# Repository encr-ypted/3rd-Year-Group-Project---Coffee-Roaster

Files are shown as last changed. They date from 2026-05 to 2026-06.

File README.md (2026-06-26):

# Smart Coffee Roaster

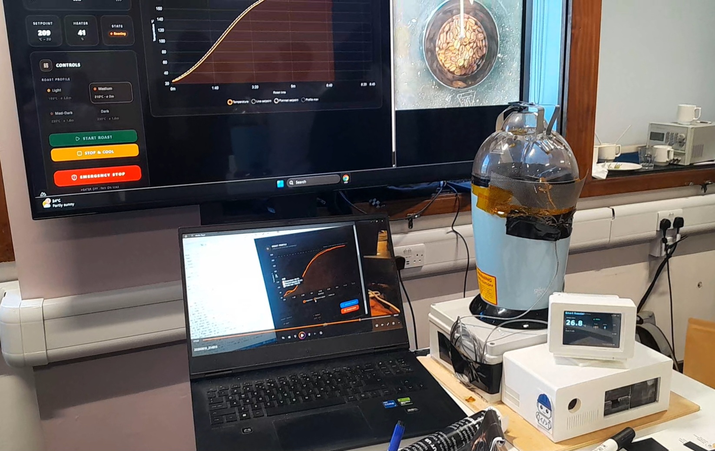
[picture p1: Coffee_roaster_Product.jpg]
Complete Smart Coffee Roaster


> **A low-cost AI-enabled Smart Coffee Roaster developed as part of a third-year Electronic Engineering group project sponsored by IBM.**

The project combines **embedded systems**, **power electronics**, **control engineering**, **computer vision**, **web technologies**, and **artificial intelligence** to create an intelligent small-batch coffee roasting platform capable of automatically executing roast profiles while monitoring and logging the roasting process in real time.

---

# Table of Contents

- [Overview](#overview)
- [Project Objectives](#project-objectives)
- [Final System Features](#final-system-features)
- [Final Prototype](#final-prototype)
- [Power & Embedded Electronics Architecture](#power--embedded-electronics-architecture)
- [Control System](#control-system)
- [Dashboard](#dashboard)
- [Computer Vision & AI](#computer-vision--ai)
- [Hardware](#hardware)
- [Repository Structure](#repository-structure)
- [Detailed Backend Documentation](#detailed-backend-documentation)
- [Future Development](#future-development)
- [Team Members](#team-members)
- [Sponsor](#sponsor)
- [Disclaimer](#disclaimer)

---

# Overview

Coffee roasting is a highly dynamic thermal process where temperature, airflow and bean properties continuously change throughout the roast. Achieving consistent roast quality requires accurate temperature measurement together with precise heater and airflow control.

This project began with a commercially available **hot-air popcorn popper** before being extensively redesigned into a complete embedded coffee roasting platform.

The final system integrates:

- Adaptive Model Predictive Control (MPC)
- Automatic preheating
- Automatic bean-drop detection
- Closed-loop heater control
- Variable-speed blower control
- Live browser dashboard
- Roast profile execution
- Roast data logging
- Raspberry Pi camera monitoring
- Computer vision using grayscale analysis
- Multiple hardware and software safety systems

The primary objective of the project was to develop an accessible and low-cost coffee roasting platform capable of producing more consistent roasts while demonstrating modern embedded control techniques.

---

---

# Overall System Architecture

The Smart Coffee Roaster consists of four primary subsystems:

1. Embedded Control
2. Power Electronics
3. Computer Vision
4. User Interface

The interaction between these subsystems is shown below.

```text
                         ┌──────────────────────────┐
                         │      Web Dashboard       │
                         │  (Vue.js Frontend)       │
                         └────────────┬─────────────┘
                                      │
                            WebSocket / REST API
                                      │
                                      ▼
                         ┌──────────────────────────┐
                         │     FastAPI Backend      │
                         │     (webserver.py)       │
                         └──────┬──────────┬────────┘
                                │          │
                    Commands     │          │ Telemetry
                                ▼          ▲
                     ┌────────────────────────────┐
                     │      MPC Controller        │
                     │      (MPC_Control.py)      │
                     └──────┬────────────┬────────┘
                            │            │
                 Heater PWM │            │ Fan PWM
                            ▼            ▼
                      ┌────────┐    ┌────────┐
                      │ Heater │    │ Blower │
                      └────┬───┘    └────┬───┘
                           │             │
                           └──────┬──────┘
                                  ▼
                       ┌────────────────────┐
                       │ Coffee Roaster     │
                       │ & Roasting Chamber │
                       └─────────┬──────────┘
                                 │
                      Bean Temperature
                                 │
                                 ▼
                     ┌────────────────────┐
                     │ K-Type Thermocouple│
                     │     + MAX31855     │
                     └─────────┬──────────┘
                               │
                               ▼
                      Temperature Feedback

             ┌────────────────────────────────────────┐
             │ Raspberry Pi Camera                    │
             └────────────────┬───────────────────────┘
                              │
                              ▼
                     grayscale.py
                              │
                     Mean Grayscale
                              │
                              ▼
                     MPC Controller
```

The controller continuously receives temperature measurements from the thermocouple while simultaneously monitoring bean colour using the Raspberry Pi camera. The FastAPI backend acts as the communication layer between the embedded controller and the browser dashboard, streaming telemetry and forwarding user commands. The Adaptive Model Predictive Controller (MPC) calculates the optimum heater output every second while controlling the blower motor and logging roast data throughout the roasting process.

# Project Objectives

The objectives of this project were to:

- Design and manufacture a safe embedded coffee roasting system.
- Develop a closed-loop temperature controller capable of accurately tracking roast profiles.
- Investigate Model Predictive Control (MPC) for coffee roasting.
- Integrate computer vision for roast monitoring.
- Develop a modern browser-based user interface.
- Improve roast consistency while maintaining a low overall system cost.
- Produce a modular platform suitable for future AI-assisted roast optimisation.

---

# Final System Features

## Embedded Control

- Raspberry Pi based control system
- Closed-loop heater control
- Variable-speed blower control
- Automatic preheat sequence
- Automatic bean-drop detection
- Adaptive Model Predictive Control
- Automatic cooling mode
- Emergency stop functionality

## User Interface

- Browser-based dashboard
- Live temperature graph
- Planned roast profile
- Actual roast profile
- Roast profile presets
- Heater output display
- Fan state display
- Camera livestream
- Roast logging

## Computer Vision

- Raspberry Pi Camera integration
- Bean detection
- Region-of-interest extraction
- Mean grayscale calculation
- Roast monitoring

## Safety

- Hardware emergency stop
- Software emergency stop
- Over-temperature protection
- Fan fail-safe design
- Isolated high-voltage enclosure
- Separate low-voltage control enclosure

---

# Final Prototype

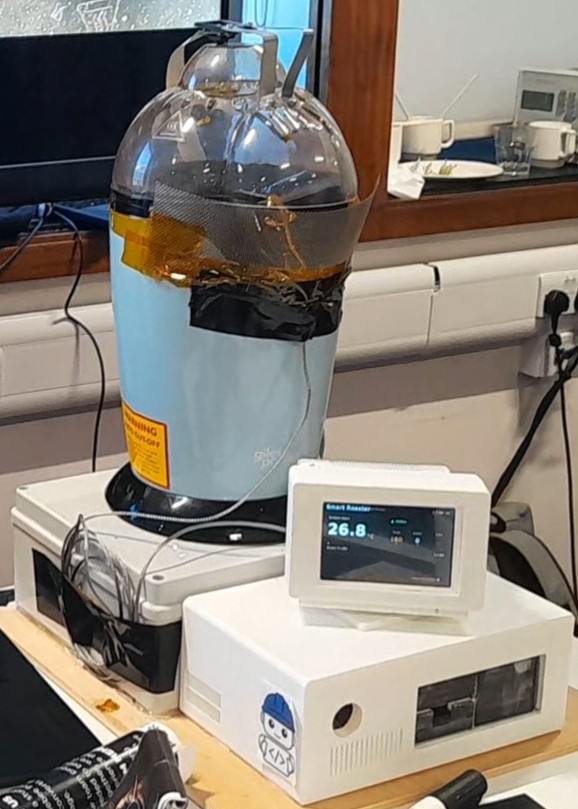
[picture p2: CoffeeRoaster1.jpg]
Complete Prototype


The completed prototype integrates the roasting chamber, embedded electronics, screen display, Raspberry Pi camera and browser-based dashboard into a fully functional coffee roasting system.

The Raspberry Pi continuously monitors bean temperature using a K-type thermocouple before executing the selected roast profile using an Adaptive Model Predictive Controller (MPC). Throughout the roast, telemetry is streamed to the dashboard where the user can monitor live temperature, heater output, fan state, roast progress and the camera feed.

All roast data is logged for later analysis and future controller development.

---

# Power & Embedded Electronics Architecture

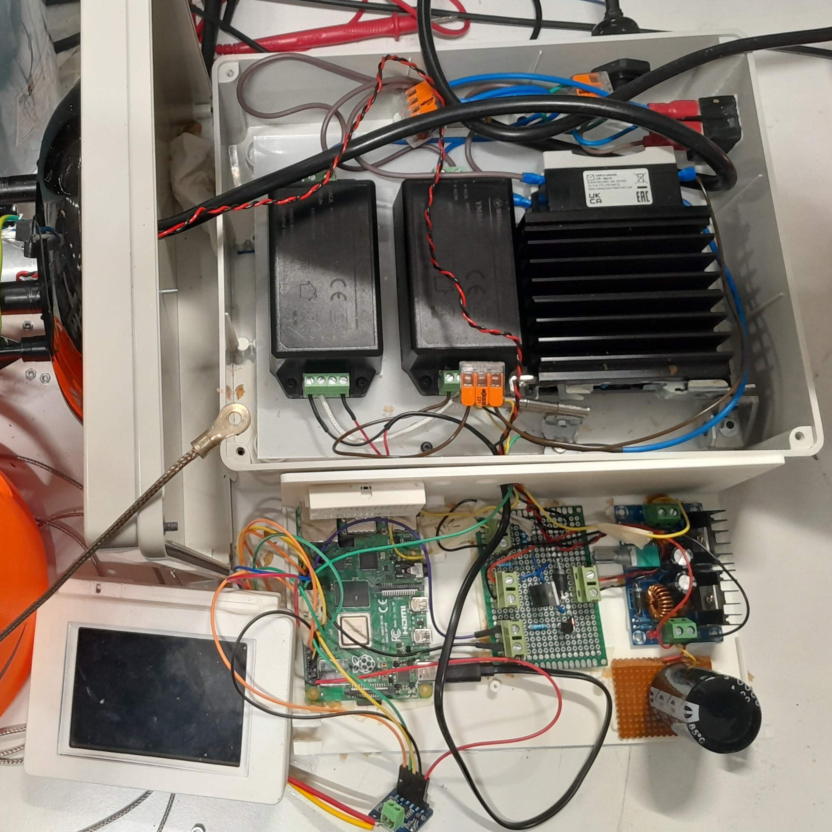
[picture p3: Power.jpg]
Power Electronics Architecture


To improve electrical safety and simplify maintenance, the electronics were deliberately divided into separate **high-voltage** and **low-voltage** enclosures.

This separation prevents hazardous mains wiring from being mixed with sensitive control electronics while reducing electrical interference and improving serviceability.

## High-Voltage Enclosure

The upper enclosure contains every mains-powered component used by the roasting system, including:

- AC → 24 V DC power supply for the blower motor
- AC → 5 V DC power supply for the Raspberry Pi
- Solid State Relay (SSR)
- Aluminium heatsink mounted to the SSR
- Heater switching circuitry
- Mains wiring
- Terminal blocks

The Solid State Relay allows the Raspberry Pi to safely switch the heating element while maintaining complete electrical isolation from the mains supply.

Because the SSR dissipates heat during operation, it is mounted to an aluminium heatsink to maintain safe operating temperatures during long roasting cycles.

Locating every mains-powered component inside a dedicated enclosure significantly reduces the risk of accidental contact with hazardous voltages while making the electrical system considerably easier to maintain and troubleshoot.

---

## Low-Voltage Control Enclosure

The lower enclosure contains all embedded control electronics responsible for monitoring and controlling the roasting process.

Components include:

- Raspberry Pi 4
- MAX31855 thermocouple interface
- Custom motor driver Circuit
- Raspberry Pi screen display
- 24 V → 6.2 V buck converter supplying the blower motor
- Large smoothing capacitor connected to the buck converter output

The buck converter efficiently steps the 24 V supply down to approximately **6.2 V** for the blower motor.

A large output smoothing capacitor is connected across the converter output to reduce voltage ripple and improve supply stability during rapid motor load changes.

The separation between high-voltage and low-voltage electronics also improves measurement stability by reducing electrical noise reaching the thermocouple interface and Raspberry Pi.

# Custom Motor Driver

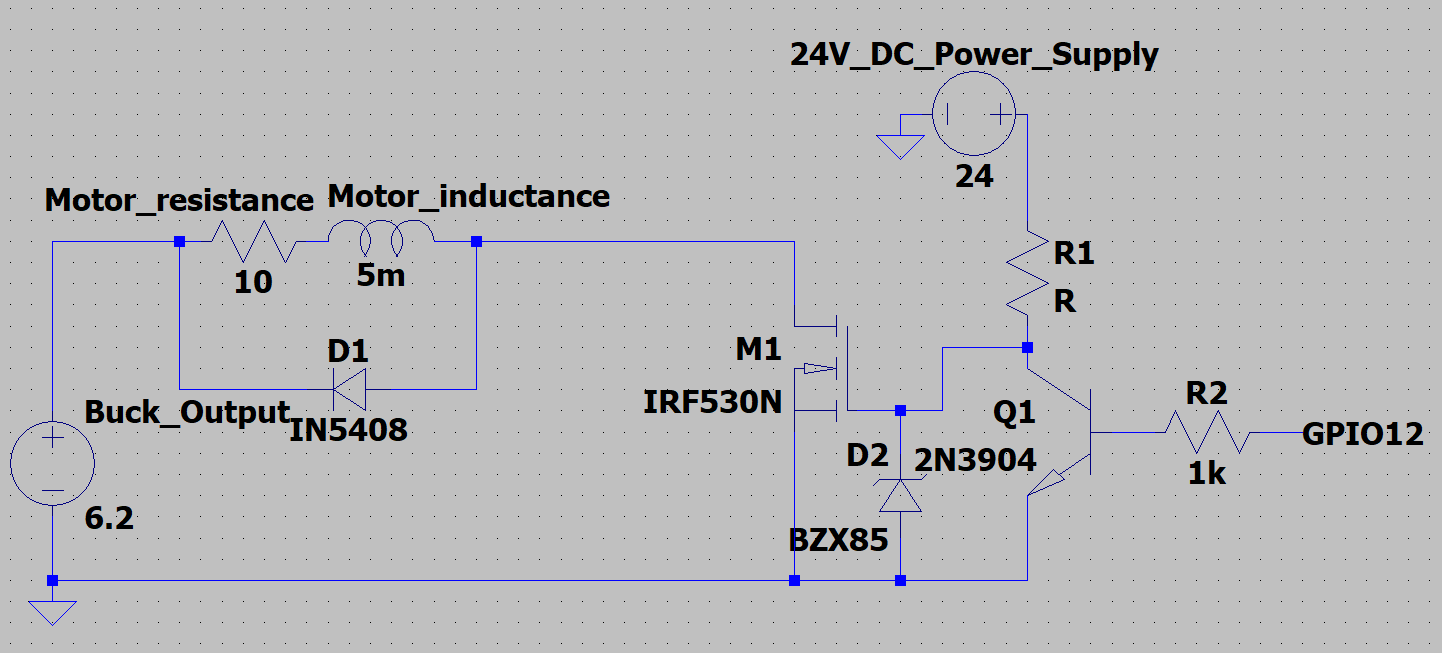
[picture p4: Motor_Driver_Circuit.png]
Motor Driver Circuit


Rather than using a commercial motor driver module, a custom Circuit was designed specifically for the requirements of this project.

The driver controls the fan motor while incorporating additional hardware safety features that operate independently of the Raspberry Pi software.

## BJT Fail-Safe Design

One of the primary safety considerations during development was ensuring continuous airflow over the heater.

If the Raspberry Pi were to crash, lose power or become disconnected while the heater remained hot, stopping the fan (blower) could allow excessive temperatures to develop inside the roasting chamber, which results in melting the fan.

To minimise this risk, the motor driver incorporates a **BJT-based fail-safe circuit**.

The circuit is designed so that:

- During normal operation the Raspberry Pi controls the fan speed.
- If the Raspberry Pi loses power or becomes disconnected, the control transistor automatically defaults the fan **ON**.
- Continuous airflow cools the heater while preventing excessive heat build-up inside the roasting chamber.

Unlike software safety mechanisms, this protection remains operational even if the Raspberry Pi itself has failed, providing an additional hardware layer of protection.

---

# Control System

Temperature is measured using a **K-type thermocouple** connected to a **MAX31855 thermocouple interface**.

The roasting process is controlled using an **Adaptive Model Predictive Controller (MPC)** rather than a conventional PID controller.

Coffee roasting is a challenging control problem because:

- the system exhibits significant thermal inertia,
- heater power takes several seconds to affect bean temperature,
- bean properties continuously change throughout the roast,
- moisture evaporates,
- airflow conditions vary,
- heat losses change over time.

A controller that reacts only to the current temperature error therefore struggles to accurately follow a continuously changing roast profile.

Instead, the implemented MPC predicts how the bean temperature will evolve in the future before selecting the optimum heater output.

The controller performs:

- Automatic chamber preheating
- Automatic bean-drop detection
- Future roast profile prediction
- Heater optimisation
- Adaptive thermal model updating
- Overshoot minimisation
- Smooth heater control
- Automatic cooling mode

Every second the controller:

1. Reads the current bean temperature.
2. Predicts future bean temperatures across the prediction horizon.
3. Generates the future sigmoid roast-profile setpoints.
4. Evaluates every possible heater duty cycle.
5. Calculates the optimisation cost for every candidate.
6. Selects the heater output with the minimum predicted cost.
7. Applies the selected heater duty cycle.
8. Updates the adaptive thermal model when required.

As roasting progresses, the thermal behaviour of the beans changes due to moisture evaporation, changing bean density and varying airflow conditions.

To compensate for these effects, the controller continuously adapts its thermal model by updating the heater effectiveness parameter whenever sustained prediction errors are observed.

This enables the controller to maintain accurate temperature prediction throughout the roast.

The complete mathematical derivation, optimisation equations, thermal model and implementation are documented separately in the backend documentation: [`Backend_Final_Version/README.md`](Backend_Final_Version/README.md).

---

# Dashboard

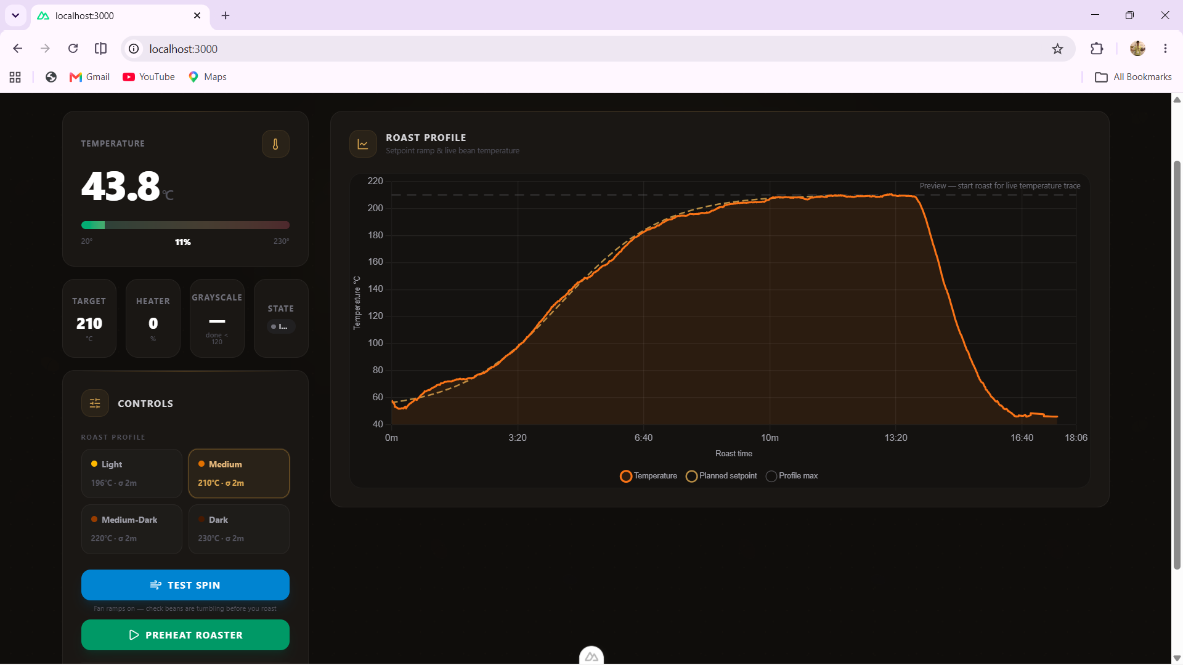
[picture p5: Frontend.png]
Frontend


A browser-based dashboard was developed to provide complete control and monitoring of the roasting process.

The interface communicates directly with the Raspberry Pi backend using WebSockets, allowing telemetry to be updated in real time.

The dashboard displays:

- Live bean temperature
- Planned roast profile
- Actual roast profile
- Heater duty cycle
- Fan duty cycle
- Current operating state
- Roast timer
- Roast presets

The user can also:

- Start a roast
- Stop and cool the roast
- Perform an emergency stop
- Test the fan (blower) motor
- Select predefined roast profiles

All roast telemetry is continuously logged and stored for later analysis.

---

# Computer Vision & AI

A Raspberry Pi Camera continuously monitors the roasting chamber throughout the roast.

Current functionality includes:

- Live video streaming
- Bean detection
- Region-of-interest extraction
- Mean grayscale calculation
- Roast monitoring
- Roast logging

The average bean grayscale value is continuously calculated and compared against profile-dependent thresholds.

This information can be used to notify the operator when the beans appear to have reached the desired roast level.

The vision system has been deliberately separated from the main controller so that camera failures cannot interrupt heater control or other safety-critical functions.

The software architecture also allows future integration of machine learning models capable of automatically classifying roast level and recommending or terminating roasts.

---

# Hardware

The completed prototype consists of:

## Mechanical

- Modified hot-air popcorn popper
- Custom PETG blower fan
- 3D printed mechanical components
- Protective electronics enclosures

## Embedded Electronics

- Raspberry Pi 4
- Raspberry Pi Camera
- Raspberry Pi screen display
- MAX31855 thermocouple interface
- K-type thermocouple
- Custom motor driver Circuit

## Power Electronics

- AC → 24 V DC power supply
- AC → 5 V DC power supply
- Solid State Relay (SSR)
- Aluminium heatsink
- 24 V → 6.2 V buck converter
- Output smoothing capacitor

---

# Repository Structure

```text
.
├── README.md                         <- Main project overview
│
├── backend_final_version/
│   ├── README.md                     <- Detailed MPC documentation
│   ├── MPC_Control.py
│   ├── grayscale.py
│   ├── webserver.py
│   ├── st7796.py
│   └── ...
│
├── blog/
│   ├── progress-update-7th-may.md
│   ├── progress-update-21st-may.md
│   └── progress-update-7th-june.md
│
├── Coffee_roaster_Product.jpg
├── Power.jpg
└── ...
```

## Detailed Backend Documentation

The backend implementation, including:

- Adaptive Model Predictive Control (MPC)
- Thermal model
- Optimisation equations
- Software architecture
- FastAPI backend
- Dashboard communication
- Camera processing
- Backend safety systems

is documented in:

➜ **[`Backend_Final_Version/README.md`](Backend_Final_Version/README.md)**

# Future Development

Although the current system is fully functional, several opportunities exist for future improvement.

Potential future work includes:

- Automatic roast completion using computer vision
- Convolutional Neural Network (CNN) based roast-level classification
- Automatic roast profile optimisation using machine learning
- Roast profile recommendation based on previous roasting data
- Multi-sensor thermal modelling
- Automatic parameter tuning for the MPC controller
- Cloud-based roast logging and analytics
- Remote monitoring and control
- Mobile application integration
- Expansion to larger-capacity roasting systems

The modular hardware and software architecture developed during this project was intentionally designed to support these future extensions with minimal modification to the existing control system.

---

# Sustainability

Coffee roasting is traditionally a highly experience-dependent process where inconsistent temperature control can result in wasted batches of coffee.

This project aims to improve sustainability by:

- Reducing roasting waste through improved temperature control
- Improving roast repeatability
- Providing an accessible low-cost roasting platform
- Supporting small-batch roasting
- Reducing unnecessary energy consumption through adaptive heater control
- Providing detailed roast data for process optimisation

The use of Model Predictive Control (MPC) further improves energy efficiency by applying only the heater power required to accurately follow the desired roast profile rather than continuously oscillating around the target temperature.

---

# Learning Outcomes

This project involved the integration of multiple engineering disciplines, including:

- Embedded Systems
- Control Engineering
- Power Electronics
- Software Engineering
- Computer Vision
- Mechanical Design
- 3D Printing
- Data Logging
- Web Development

The final prototype demonstrates the successful integration of these disciplines into a complete embedded coffee roasting platform.

---

# Project Outcome

The project successfully produced a fully operational AI-enabled smart coffee roaster capable of:

- Automatic preheating
- Automatic bean-drop detection
- Closed-loop temperature control
- Adaptive Model Predictive Control
- Roast profile tracking
- Live dashboard monitoring
- Camera-based roast monitoring
- Roast logging
- Automatic cooling
- Hardware and software safety mechanisms

Multiple successful roasting trials were completed throughout the project, demonstrating accurate temperature tracking and repeatable roast profile execution.

The completed system provides a modular platform suitable for continued research into intelligent coffee roasting and future AI-assisted optimisation techniques.

---

# Team Members

This project was completed by:

- Sami Marouf
- Tayo Babs-Olugbemi
- Rojan Ragunathan
- Patanwit Sawatyanon
- Yikai Su
- Peter Z Wang

---

# Sponsor

This project was completed as part of a third-year Electronic Engineering Group Design Project with sponsorship and support from **IBM**.

IBM provided industrial guidance throughout the project, helping shape the system requirements, design process and final implementation.

---

# Acknowledgements

The team would like to thank:

- IBM for sponsoring and supporting the project.
- The Department of Electronic Engineering for providing laboratory facilities and technical guidance.
- The project supervisor and lab technicians for their continuous feedback throughout the design and testing process.

---

# Disclaimer

This project interfaces with **mains electricity**, **high temperatures**, and **moving mechanical components**.

The prototype was developed for educational and research purposes.

Although numerous hardware and software safety mechanisms were incorporated—including electrical isolation, emergency stop functionality, over-temperature protection, hardware blower fail-safe circuitry and automatic cooling—the system should only be operated using appropriate electrical protection and under suitable supervision.

The authors accept no responsibility for any damage or injury resulting from attempts to reproduce or operate this system without appropriate engineering knowledge and safety precautions.

---

# Detailed Backend Documentation

The complete backend implementation—including:

- Adaptive Model Predictive Control (MPC)
- Mathematical derivation of the controller
- Thermal process model
- Optimisation cost function
- Adaptive thermal model
- FastAPI backend
- Dashboard communication
- Camera processing pipeline
- Safety mechanisms
- Backend architecture

is documented separately in:

## ➜ **[`Backend_Final_Version/README.md`](Backend_Final_Version/README.md)**

This document provides a detailed explanation of the control algorithms, mathematical equations, software architecture and implementation used by the Smart Coffee Roaster.

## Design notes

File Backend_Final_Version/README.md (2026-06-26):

# Smart Coffee Roaster Backend

This folder contains the Raspberry Pi backend for the Smart Coffee Roaster. It controls the roast process, communicates with the frontend, monitors bean brightness with the camera, and can drive the optional LCD display.

## Files

### `MPC_Control.py`

The main roast-control script.

It:
- Reads temperature from the MAX31855 thermocouple.
- Controls the heater and fan.
- Handles preheating, bean-drop detection, and the normal roast phase.
- Uses a model predictive control (MPC) loop to follow the selected roast profile's setpoint curve.
- Writes roast telemetry to CSV files in `logs/`.
- Reads grayscale data from `grayscale_state.json`.
- Sends a roast-done notification flag when grayscale stays below the selected profile threshold for five seconds.

The grayscale notification does not automatically stop the roast, turn off the heater, or start cooling.

### `grayscale.py`

A separate camera worker for the Raspberry Pi AI camera.

It:
- Starts the camera and AI detector.
- Captures bean images.
- Calculates the average bean brightness (`mean_grayscale`).
- Writes the latest value to `grayscale_state.json`.

It runs separately from `MPC_Control.py` so camera errors, timeouts, or crashes do not interrupt the main heating, fan, thermocouple, or MPC control logic.

A grayscale value ranges from approximately 0 to 255:
- Lower values mean darker beans.
- Higher values mean lighter beans.

### `webserver.py`

The FastAPI/WebSocket backend used by the frontend.

It:
- Provides roast profiles at `/api/profiles`.
- Sends live telemetry through `/ws/telemetry`.
- Reads the newest CSV file in `logs/`.
- Sends temperature, setpoint, heater output, fan output, grayscale, roast state, and roast-done notification status to the frontend.
- Writes commands to `roaster_command.json`.

### `st7796.py`

Driver for the ST7796 SPI LCD display.

It uses SPI1 so it does not conflict with the MAX31855 thermocouple on SPI0.

### `requirements.txt`

Python dependencies for the backend.

## Adaptive Model Predictive Control (MPC)

The Smart Coffee Roaster uses an **Adaptive Model Predictive Controller (MPC)** to regulate bean temperature throughout the roast. Unlike a conventional PID controller, which reacts only to the current temperature error, the MPC predicts the future thermal behaviour of the roaster before selecting the optimum heater output. This approach is particularly well suited to coffee roasting because the process exhibits significant thermal inertia and transport delay, meaning changes in heater power may take several seconds to influence bean temperature.

At every one-second control interval, the controller predicts how the bean temperature will evolve over a finite prediction horizon using a first-order discrete thermal model. Multiple candidate heater outputs are evaluated, and the one producing the lowest overall cost is selected and applied for the next control interval. This optimisation process is repeated every second throughout the roast.

### Thermal Process Model

The roaster is approximated using the first-order discrete thermal model

$$
T_{k+1}=T_{amb}+A(T_k-T_{amb})+Bu_k
$$

where:

* **Tₖ** = current bean temperature
* **Tₖ₊₁** = predicted bean temperature one second later
* **Tₐₘᵦ** = ambient temperature
* **uₖ** = heater duty cycle (%)
* **A** = heat retention coefficient
* **B** = heater effectiveness coefficient

The first term represents the ambient temperature surrounding the roaster.

The second term models the thermal inertia of the roasting system by describing how much of the previous temperature is naturally retained between consecutive control intervals.

The third term represents the heating contribution from the electric heater. Larger heater duty cycles produce greater increases in predicted bean temperature.

Rather than using this model only once, the MPC repeatedly evaluates it to predict the complete future temperature trajectory.

### Future Setpoint Prediction

Instead of assuming the future target temperature remains equal to the current setpoint, the controller predicts the actual future roast profile.

For every prediction step,

$$
r_{k+i}=\text{SetpointCurve}(t+i)
$$

where:

* **rₖ₊ᵢ** = desired future temperature
* **t** = current roast time
* **i** = prediction step

This allows the controller to anticipate future temperature changes before they occur. As the sigmoid roast profile continues to rise, the MPC can begin increasing heater power in advance rather than waiting until the setpoint has already changed.

### Prediction Horizon

For each control interval, the controller predicts bean temperature over a finite prediction horizon of approximately one minute.

For every candidate heater duty cycle between **0% and 100%**, the thermal model is recursively evaluated to generate the complete future temperature trajectory

$$
{T_{k+1},T_{k+2},...,T_{k+N}}
$$

where **N** is the prediction horizon.

This enables the controller to compare the long-term consequences of different heater outputs rather than considering only the next measurement.

### Candidate Heater Evaluation

At every control update, the controller evaluates every possible heater duty cycle from **0% to 100%**.

For each candidate heater output:

1. The future roast-profile setpoints are generated.
2. Future bean temperatures are predicted across the prediction horizon.
3. A total optimisation cost is calculated.
4. The controller stores the total cost.

After all candidate heater outputs have been evaluated, the heater duty cycle with the lowest predicted cost is selected and applied.

Mathematically,

$$
u^*=\arg\min_u J(u)
$$

where **u*** represents the optimum heater duty cycle.

### Cost Function

Each candidate heater output is assigned a cost according to

$$
J=\sum_{k=1}^{N}w_t(r_k-T_k)^2+\sum_{k=1}^{N}w_oO_k^2+w_h(u_k-u_{k-1})^2
$$

where:

* **wₜ** = tracking-error weighting
* **wₒ** = overshoot weighting
* **wₕ** = heater-change weighting

#### Tracking Error

The first term

$$
\sum_{k=1}^{N}w_t(r_k-T_k)^2
$$

penalises deviation between the predicted bean temperature and the desired roast profile throughout the prediction horizon. Larger tracking errors produce larger costs, encouraging the controller to follow the planned roast profile as accurately as possible.

#### Overshoot Penalty

The second term

$$
\sum_{k=1}^{N}w_oO_k^2
$$

penalises predicted overshoot above the desired roast profile.

Only temperatures exceeding the target contribute to this penalty, discouraging overheating while still allowing aggressive heating when the measured temperature remains below the desired profile.

#### Heater Smoothness

The third term

$$
w_h(u_k-u_{k-1})^2
$$

penalises large changes in heater duty cycle between consecutive control intervals.

Without this penalty, the optimiser may rapidly increase and decrease heater power, producing oscillatory behaviour. Penalising abrupt heater changes results in smoother control actions, reduced actuator switching, and improved thermal stability.

### Adaptive Thermal Model

Coffee roasting is not a constant thermal process.

During roasting:

- moisture evaporates,
- bean density decreases,
- airflow characteristics change,
- heat losses vary,
- the effectiveness of the heater changes.

Consequently, a fixed thermal model gradually becomes inaccurate.

To compensate, the controller continuously compares predicted and measured temperatures.

If a sustained prediction error is detected, the heater effectiveness coefficient (**B**) is automatically adjusted within predefined minimum and maximum limits.

If the measured temperature rises faster than predicted, the controller increases **B**, indicating that the heater is more effective than previously estimated.

If the measured temperature rises more slowly than predicted, **B** is reduced.

This adaptive mechanism continually improves model accuracy throughout the roast while preventing unrealistic parameter values.

### Bean-Drop Detection

Before roasting begins, the chamber is preheated to the selected temperature.

When green coffee beans are added, the thermocouple detects the characteristic temperature drop caused by the colder beans entering the chamber.

The controller automatically identifies this event, temporarily suspends normal roast control, waits until the temperature reaches its minimum, and detects the point at which the beans begin warming again.

At this instant:

- the roast timer is reset,
- the sigmoid roast profile begins,
- the MPC controller becomes active.

This ensures the roast profile is synchronised with the true start of bean heating rather than the preheating stage.

### Control Cycle

Every second the controller performs the following sequence:

1. Read the current bean temperature from the thermocouple.
2. Generate future sigmoid roast-profile setpoints.
3. Predict future bean temperatures for every candidate heater output.
4. Calculate the optimisation cost for every candidate.
5. Select the heater duty cycle producing the minimum cost.
6. Apply the selected heater output.
7. Update the adaptive heater-effectiveness coefficient if required.
8. Record telemetry for the dashboard and CSV log files.

This optimisation process repeats continuously throughout the roast, allowing the controller to accurately track a continuously changing roast profile while automatically compensating for changing thermal dynamics.

## Roast Flow

1. The empty roasting chamber is preheated.
2. Once the preheat temperature is stable, beans are added.
3. The added beans create a temperature drop.
4. The controller detects the drop, turns the heater off, and waits for the lowest temperature.
5. Once the temperature begins rising again, the actual roast starts.
6. The controller resets roast time and follows the MPC setpoint curve toward the chosen profile target.

## Grayscale Roast-Done Notification

The camera worker measures the average brightness of the beans and writes it to `grayscale_state.json`.

During the actual roast, `MPC_Control.py` compares that value against the selected profile threshold:

| Roast profile | Notification threshold |
|---|---:|
| Light | Below 120 |
| Medium | Below 115 |
| Medium-Dark | Below 110 |
| Dark | Below 105 |

If the grayscale value remains below the selected threshold for five seconds, the backend sets `roast_done` to `true`. The frontend can then display a notification that the roast looks done.

This is notification-only. The user still decides when to stop and cool the roast.

## Running the Backend

Open three terminals on the Raspberry Pi.

### 1. Start the grayscale worker

```bash
source venv/bin/activate
python grayscale.py
```

This writes live camera data to:

```text
grayscale_state.json
```

### 2. Start the roast controller

```bash
source venv/bin/activate
python MPC_Control.py
```

This controls the thermocouple, heater, fan, preheat sequence, bean-drop detection, MPC setpoint curve, and roast logging.

### 3. Start the web server

```bash
source venv/bin/activate
python webserver.py
```

The server runs on port `8000`.

### 4. Start the screen display

```bash
source venv/bin/activate
python lcd.py
```

## Generated Files

### `roaster_command.json`

Written by `webserver.py` and read by `MPC_Control.py`.

Example:

```json
{
  "command": "PREHEAT",
  "target_c": 210.0,
  "profile_id": "medium"
}
```

### `grayscale_state.json`

Written by `grayscale.py` and read by `MPC_Control.py`.

Example:

```json
{
  "timestamp": 1712345678.2,
  "mean_grayscale": 94.7,
  "ok": true,
  "error": null
}
```

### `logs/roast_*.csv`

Created by `MPC_Control.py`.

Each CSV row includes time, temperature, target, setpoint, heater output, fan speed, grayscale value, grayscale threshold, roast-done notification status, and control state.

## Safety Notes

- The grayscale system is notification-only and must not replace operator judgement.
- The emergency-stop and over-temperature safety behavior remain in `MPC_Control.py`.
- If the camera worker stops, the main roast controller continues running. Grayscale will appear unavailable until the worker starts writing fresh values again.

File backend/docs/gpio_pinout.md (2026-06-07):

# Raspberry Pi GPIO pinout — Coffee Roaster

Wiring reference for the **40-pin Raspberry Pi header**. All GPIO numbers are **BCM** (Broadcom), not board/WiringPi numbering.

Physical pin numbers match the standard Pi pinout (pin 1 = 3.3 V at the corner near the SD card, odd pins on the left column).

Config source: `config.py` (heater, fan, thermocouple) and `hardware/display/st7796.py` (LCD).

---

## Quick reference — all used pins

| Component | Signal | BCM GPIO | Physical pin | SPI / bus |
|---|---|---|---|---|
| **Heater** | SSR control | **23** | **16** | — |
| **Fan** | PWM speed | **12** | **32** | — |
| **Thermocouple** | CS (CE1) | **7** | **26** | SPI0 |
| **Thermocouple** | SCLK | **11** | **23** | SPI0 |
| **Thermocouple** | MISO (DO) | **9** | **21** | SPI0 |
| **Thermocouple** | MOSI | **10** | **19** | SPI0 (shared; MAX31855 reads via MISO) |
| **LCD** | CS | **17** | **11** | SPI1 (`/dev/spidev1.0`) |
| **LCD** | MOSI (SDI) | **20** | **38** | SPI1 |
| **LCD** | SCLK (SCK) | **21** | **40** | SPI1 |
| **LCD** | MISO (SDO) | **19** | **35** | SPI1 (optional) |
| **LCD** | DC / RS | **25** | **22** | — |
| **LCD** | RESET / RST | **24** | **18** | — |
| **LCD** | Backlight (BL) | **22** | **15** | — |
| **Power** | 3.3 V (sensors, LCD) | — | **1** or **17** | — |
| **Power** | 5 V (if module needs it) | — | **2** or **4** | — |
| **Ground** | Common GND | — | **6**, **9**, **14**, **20**, **25**, **30**, **34**, **39** | — |

**12 GPIO lines used** (7, 9, 10, 11, 12, 17, 20, 21, 22, 23, 24, 25). MISO on GPIO 19 is optional for the LCD.

---

## Do not use (conflicts)

| BCM GPIO | Physical pin | Why |
|---|---|-----|
| **18** | **12** | Default SPI1 CE0 — remapped to GPIO 17 for this project |
| **8** | **24** | SPI0 CE0 — thermocouple uses **CE1** (GPIO 7) instead |

Do not move the heater to GPIO 18; firmware and docs assume **GPIO 23** (pin 16). LCD backlight is **GPIO 22** (pin 15), not 23.

---

## Heater (SSR)

Solid-state relay driven by time-proportional software (`hardware/devices/heater.py`).

| From | To | BCM GPIO | Physical pin |
|---|-----|---|---|
| Pi GPIO | SSR control input (+) | **23** | **16** |
| Pi GND | SSR control input (−) / module GND | — | e.g. **6**, **14**, **20** |

| Property | Value |
|---|---|
| `config.py` | `HEATER_GPIO = 23` |
| Logic | Active **high** — GPIO high = heater on for the current PWM window |
| Control | ~1 s window, duty 0–100% (`HEATER_CONTROL_WINDOW_S`) |

Use an SSR rated for your heater load. Keep mains wiring separate from low-voltage Pi wiring.

---

## Fan (PWM)

Drum / cooling fan via PWM (`hardware/devices/motor.py`).

| From | To | BCM GPIO | Physical pin |
|---|-----|---|---|
| Pi PWM output | Fan driver (MOSFET gate / PWM input) | **12** | **32** |
| Pi GND | Driver GND | — | any GND |

| Property | Value |
|---|---|
| `config.py` | `FAN_PWM_GPIO = 12`, `FAN_PWM_FREQUENCY_HZ = 1000` |
| Logic | `active_high=False` — software uses inverted PWM; verify spin direction/speed on the bench |
| Default | 100% when on (`FAN_DEFAULT_SPEED = 1.0`) |

GPIO 12 supports hardware PWM (PWM0). Use a suitable transistor or MOSFET if the fan draws more than a few milliamps from the Pi.

---

## Bean temperature (MAX31855 thermocouple)

SPI0 + chip select on CE1 (`hardware/devices/thermocouple.py`, Adafruit MAX31855 library).

### Module → Pi

| MAX31855 label | Pi signal | BCM GPIO | Physical pin |
|---|---|---|---|
| VIN / VCC | 3.3 V | — | **1** or **17** |
| GND | GND | — | e.g. **9**, **14** |
| SCK / CLK | SPI0 SCLK | **11** | **23** |
| CS | SPI0 CE1 | **7** | **26** |
| SO / DO (data out) | SPI0 MISO | **9** | **21** |

| Property | Value |
|---|---|
| `config.py` | `THERMOCOUPLE_CS_GPIO = 7` |
| Device node | Uses `board.SPI()` → `/dev/spidev0.0` with manual CS on GPIO 7 |
| Probe | K-type (or match your breakout board) |

After wiring, confirm SPI0:

```bash
ls /dev/spidev0.0
```

Enable with `dtparam=spi=on` in `/boot/firmware/config.txt` (or `/boot/config.txt` on older OS).

---

## LCD (ST7796, 3.5″ SPI)

Separate **SPI1** bus so LCD traffic does not share SPI0 with the thermocouple (`hardware/display/st7796.py`).

### Required boot config

In `/boot/firmware/config.txt` (Bookworm) or `/boot/config.txt`:

```text
dtparam=spi=on
dtoverlay=spi1-1cs,cs0_pin=17
```

Reboot, then check:

```bash
ls /dev/spidev1.0
```

### LCD module → Pi

| LCD label | Pi signal | BCM GPIO | Physical pin | Notes |
|---|---|---|---|---|
| VCC | 3.3 V | — | **1** or **17** | Use 5 V only if your module docs require it |
| GND | GND | — | e.g. **6**, **9** | |
| CS / LCD_CS | SPI1 CS (remapped) | **17** | **11** | **Not** pin 12 (GPIO 18) |
| RESET / RST | GPIO out | **24** | **18** | |
| DC / RS | GPIO out | **25** | **22** | Data vs command |
| SDI / MOSI | SPI1 MOSI | **20** | **38** | |
| SCK / SCLK | SPI1 SCLK | **21** | **40** | |
| LED / BL | Backlight | **22** | **15** | PWM brightness in software |
| SDO / MISO | SPI1 MISO | **19** | **35** | Optional for display-only |
| Touch (T_*) | — | — | — | Not connected |
| SD card (SD_*) | — | — | — | Not connected |

| Property | Value |
|---|---|
| SPI | Bus **1**, device **0** → `/dev/spidev1.0` |
| Rotation | 90° landscape (default in driver) |

Smoke test: `python hardware/display/st7796.py` (from `backend/` with venv). See also `docs/lcd_st7796_test.md`.

---

## SPI bus summary

```
SPI0 (/dev/spidev0.0)          SPI1 (/dev/spidev1.0)
├── SCLK  GPIO 11  pin 23      ├── SCLK  GPIO 21  pin 40
├── MOSI  GPIO 10  pin 19      ├── MOSI  GPIO 20  pin 38
├── MISO  GPIO  9  pin 21      ├── MISO  GPIO 19  pin 35
├── CE0   GPIO  8  pin 24  (unused)
└── CE1   GPIO  7  pin 26  ← MAX31855 CS
                               └── CS    GPIO 17  pin 11  ← LCD (overlay remap)
```

---

## 40-pin header map (used pins only)

Odd pins (left) and even pins (right), top to bottom:

```
     3.3V [ 1] [ 2] 5V
          [ 3] [ 4] 5V
          [ 5] [ 6] GND
          [ 7] [ 8]
  LCD CS [11] [12] GPIO 18 — do not use for LCD CS
          [13] [14] GND
LCD BL  [15] [16] HEATER GPIO 23
   3.3V [17] [18] LCD RST GPIO 24
TC MOSI [19] [20] GND
TC MISO [21] [22] LCD DC GPIO 25
TC SCLK [23] [24] SPI0 CE0 (unused)
      GND [25] [26] TC CS GPIO 7
          [27] [28]
      GND [29] [30] GND
          [31] [32] FAN PWM GPIO 12
          [33] [34] GND
LCD MISO [35] [36]
          [37] [38] SPI1 MOSI GPIO 20
      GND [39] [40] SPI1 SCLK GPIO 21
```

---

## Changing pins in software

| Setting | File | Key |
|---|---|-----|
| Heater | `config.py` | `HEATER_GPIO` |
| Fan | `config.py` | `FAN_PWM_GPIO` |
| Thermocouple CS | `config.py` | `THERMOCOUPLE_CS_GPIO` |
| LCD CS, RST, DC, BL | `hardware/display/st7796.py` | `LCD_CS`, `LCD_RST`, `LCD_RS`, `LCD_LED` |

If you change LCD CS, update `dtoverlay=spi1-1cs,cs0_pin=...` to match and reboot.

---

## Permissions

The `pi` user (or whichever user runs the service) should be in the `gpio` and `spi` groups:

```bash
sudo usermod -aG gpio,spi pi
```

Reboot or re-login after adding groups.

---

## Related docs

- LCD bring-up: `lcd_st7796_test.md`
- Deploy on Pi: `../deploy/README.md`
- Backend overview: `../README.md`

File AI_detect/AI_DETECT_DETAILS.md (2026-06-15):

# SmartRoast AI Detection Pipeline

## Overview

This module adds the first camera-based AI workflow for the Smart Coffee Roaster project.

The system is designed for a Raspberry Pi 4B connected to a Raspberry Pi camera. The camera is mounted in a fixed position and captures images from inside the roasting chamber. The software crops a fixed region of interest, detects whether coffee beans are present, and then calculates the average grayscale value of the cropped bean region.

The grayscale value is used as an early roast colour indicator. As roasting progresses, the bean region is expected to become darker, so images captured later in the same batch should generally show a lower average grayscale value.

---

## Project Goals

* Test Raspberry Pi camera capture and image-processing behaviour
* Collect real roast image data with batch-aware file names
* Crop a fixed bean region from each captured image
* Prepare labelled datasets for bean/no-bean classification
* Apply data augmentation only to the training set
* Train and compare several lightweight CNN models using PyTorch
* Save the best-performing model locally
* Calculate average grayscale values for roast monitoring
* Generate per-batch grayscale trend plots

---

## Folder Structure

```text
AI_detect/
  01_full_system_test.py      # One-command camera and image-processing test
  02_auto_capture.py          # Timed automatic image capture during roasting
  03_crop_images.py           # Fixed ROI cropping for all captured images
  04_split_dataset.py         # 8:1:1 train/validation/test dataset split
  05_augment_train_set.py     # Training-set-only data augmentation
  06_train_models.py          # PyTorch CNN training and model comparison
  07_plot_gray_trend.py       # Per-batch grayscale trend plotting
  08_predict_image.py         # Single-image model inference
  09_pi_camera_inference.py   # CLI wrapper for live Raspberry Pi inference
  10_test_detector_loop.py    # Reusable detector loop test
  camera_utils.py             # Picamera2, OpenCV, and mock camera helpers
  grayscale_utils.py          # Reusable average grayscale calculation
  model_utils.py              # Shared CNN model definition
  pi_ai_detector.py           # Reusable detector class for backend integration
  model_config.json           # CNN architecture and training configuration
  requirements.txt            # Python dependencies
  raw/                        # Original captured images
  resized/                    # Cropped ROI images
  train_set/
  validate_set/
  test_set/
  train_set_augmented/
  models/
  plot/
  test_outputs/
```

The generated image data, plots, and model weights are ignored by `AI_detect/.gitignore` so that large local files are not committed accidentally.

---

## Technologies Used

* Raspberry Pi 4B
* Raspberry Pi camera / Picamera2
* Python
* Pillow
* NumPy
* Matplotlib
* PyTorch
* OpenCV fallback camera access

---

## Environment Setup

On Raspberry Pi OS, Picamera2 is normally installed through `apt`:

```bash
sudo apt update
sudo apt install -y python3-picamera2
```

Install the Python dependencies from this module:

```bash
cd AI_detect
python -m pip install -r requirements.txt
```

If PyTorch or OpenCV installation is slow on the Raspberry Pi, the capture, crop, grayscale, and plotting scripts can be tested first with only `Pillow`, `numpy`, and `matplotlib`. The model training script requires `torch`.

---

## Workflow

### 1. Full System Test

Run a camera and image-processing smoke test:

```bash
python 01_full_system_test.py --backend picamera2 --width 1920 --height 1080
```

For development on a laptop or on a machine without camera hardware, use the mock image generator:

```bash
python 01_full_system_test.py --mock
```

The script reports dependency availability, capture backend, image resolution, crop coordinates, grayscale output path, and the calculated mean grayscale value. Test outputs are saved in `test_outputs/`.

### 2. Automatic Data Capture

Capture images at a fixed interval during a roast:

```bash
python 02_auto_capture.py --batch-id 2026-06-08-A --interval 2 --count 180 --backend picamera2
```

Images are saved to `raw/` using batch-aware file names:

```text
batch_2026-06-08-A_shot_0001.jpg
batch_2026-06-08-A_shot_0002.jpg
```

The batch ID identifies the roast batch. The shot number identifies the image order within that batch. Use `--count 0` to keep capturing until `Ctrl+C` is pressed.

### 3. Fixed Region Cropping

After collecting a few sample images, manually inspect the frame and choose the top-left and bottom-right pixel coordinates of the bean region.

Example:

```bash
python 03_crop_images.py --x1 620 --y1 420 --x2 1280 --y2 820 --clear-output
```

To resize cropped images to a consistent CNN input size:

```bash
python 03_crop_images.py --x1 620 --y1 420 --x2 1280 --y2 820 --resize 96 96 --clear-output
```

The cropped images are saved in `resized/`, while keeping the original batch and shot naming format for later grayscale trend analysis.

### 4. Manual Labelling

The cropped images must be arranged into class folders before dataset splitting. In addition to normal bean/no-bean images, corrupted camera frames should be kept as their own class instead of being forced into either normal class:

```text
resized/
  bean/
    batch_2026-06-08-A_shot_0001.jpg
  no_bean/
    batch_empty-A_shot_0001.jpg
  corrupted/
    batch_7_shot_0330.jpg
```

At least two classes are required for training. For the current camera workflow, the recommended labels are:

* `bean` - the cropped image is valid and contains coffee beans
* `no_bean` - the cropped image is valid and does not contain coffee beans
* `corrupted` - the image is damaged, partially purple, severely blurred, overexposed, or otherwise not reliable

The `no_bean` class should include empty chamber images, startup images, and different lighting or background conditions that may occur during real operation. The `corrupted` class helps the model reject camera failures instead of treating them as valid no-bean images.

If a whole crop run belongs to one class, the crop script can place output directly into a class folder:

```bash
python 03_crop_images.py --x1 620 --y1 420 --x2 1280 --y2 820 --label bean --clear-output
```

When `--clear-output` is used without `--label`, the crop script preserves the protected label folders `bean`, `no_bean`, and `corrupted`. Root-level unlabelled crops should be moved into one of the label folders before running the split script.

### 5. Dataset Split

Split the labelled `resized/` images into training, validation, and test folders:

```bash
python 04_split_dataset.py --seed 42
```

The default split ratio is 8:1:1. The script splits each class independently and ensures that the same image is not copied into multiple datasets.

If labelled class folders and root-level unlabelled images are mixed inside `resized/`, the split script stops and asks for the root-level images to be labelled first. This prevents accidental training with incorrectly labelled data.

### 6. Data Augmentation

Generate augmented training data:

```bash
python 05_augment_train_set.py --copies-per-image 5
```

The script clears `train_set_augmented/`, copies the original training images, and adds augmented versions using small rotations, horizontal flips, light brightness variation, light Gaussian blur, and light noise. Validation and test images are not augmented so that evaluation remains realistic.

---

## Model Training

Train and compare the CNN models listed in `model_config.json`:

```bash
python 06_train_models.py
```

The training script reads:

```text
train_set_augmented/
validate_set/
test_set/
```

The training process is:

1. Train every CNN architecture defined in `model_config.json`.
2. Rank the models using validation-set performance.
3. Select the best three validation models.
4. Retrain those three models using `train_set_augmented + validate_set`.
5. Evaluate the final three models on `test_set`.
6. Save the best model to `models/best_model.pt`.
7. Save the training summary to `models/training_summary.json`.

`model_config.json` can be edited to change the input image size, batch size, number of epochs, learning rate, convolution channels, dense layers, dropout, and batch normalisation settings.

---

## Grayscale Monitoring

The average grayscale function can be imported by other scripts:

```python
from grayscale_utils import mean_grayscale

value = mean_grayscale("resized/batch_2026-06-08-A_shot_0040.jpg")
print(value)
```

The returned value is between `0` and `255`. Lower values indicate a darker image.

This should only be used as a roast-colour indicator after the image has passed the bean/no-bean classifier. If the fixed ROI does not contain beans, the grayscale value will not represent bean colour.

---

## Single Image Prediction

After training, classify one image with the saved model:

```bash
python 08_predict_image.py path/to/image.jpg --device cuda --save-debug
```

For a browser screenshot or casual phone photo that contains the camera stream inside a larger image, keep the default crop settings. The script first tries to remove the screenshot background and then applies the same centred ROI crop used by `01_full_system_test.py`.

For an original camera frame without browser UI:

```bash
python 08_predict_image.py path/to/frame.jpg --frame-crop none --roi-crop training-center --device cuda
```

For an image that is already cropped to the ROI:

```bash
python 08_predict_image.py path/to/roi.jpg --frame-crop none --roi-crop none --device cuda
```

The script prints the predicted class and probabilities for `bean`, `no_bean`, and `corrupted`. With `--save-debug`, it also saves the intermediate crops in `test_outputs/`.

---

## Raspberry Pi Deployment

The default Raspberry Pi deployment path now uses the Raspberry Pi AI Camera IMX500 `.rpk` model. Copy the converted model to:

```text
AI_detect/models/coffee_qmodel.rpk
```

The reusable detector keeps the camera and model open so inference can be called repeatedly without reloading the model:

```python
from pi_ai_detector import SmartRoastAIDetector

detector = SmartRoastAIDetector(
    model_path="AI_detect/models/coffee_qmodel.rpk",
    backend="picamera2",
)

with detector:
    result = detector.infer_once()
    print(result.to_dict())
```

The returned result includes `prediction`, class probabilities, mean grayscale, ROI coordinates, frame size, ROI size, inference time, model format, and optional crop path. This object-oriented path is the best option for backend integration.

The `09_pi_camera_inference.py` script is a command-line wrapper around the same reusable detector class. It runs the `.rpk` model by default:

```bash
python 09_pi_camera_inference.py --backend picamera2 --count 0 --interval 1 --save-crops --csv-log test_outputs/pi_inference.csv
```

The class order for the current model is expected to be:

```text
bean corrupted no_bean
```

If the exported `.rpk` uses a different output order, pass it explicitly:

```bash
python 09_pi_camera_inference.py --class-names bean corrupted no_bean
```

For laptop development or old PyTorch checkpoint testing, explicitly select the `.pt` path:

```bash
python 10_test_detector_loop.py --model-format pt --model models/best_model.pt --backend mock --count 3 --interval 2 --save-crops
```

Both scripts capture a frame, apply the fixed ROI crop for grayscale reporting, run the classifier, print class probabilities, and report the ROI mean grayscale value. If the class is `bean`, the grayscale value can be used as the roast-colour indicator. If the class is `no_bean` or `corrupted`, the grayscale value should not be used for roast-colour control.

Do not start a new Python process for every frame. Keep one `SmartRoastAIDetector` instance alive and call `infer_once()` repeatedly. Otherwise, the Raspberry Pi will repeatedly reload the `.rpk` firmware and reopen the camera.

---

## Batch Trend Plots

Generate grayscale trend plots for each roast batch:

```bash
python 07_plot_gray_trend.py
```

The script searches `resized/` for files named like:

```text
batch_<batch_id>_shot_<number>.jpg
```

For each batch, it saves:

```text
plot/batch_2026-06-08-A_gray_trend.png
plot/batch_2026-06-08-A_gray_values.csv
```

If lighting, camera position, ROI coordinates, and shot ordering are stable, later images should usually have lower grayscale values than earlier images. If a negative trend is not observed, check for glare, changing illumination, incorrect ROI selection, mixed batches, or inconsistent roast ordering.

---

## Current Status

The AI detection module currently provides the full offline workflow required to collect data, crop it, label it, split it, augment it, train candidate models, save the best model, and analyse grayscale trends.

The next integration step is to connect the saved CNN model into the live Raspberry Pi control workflow:

1. Capture a frame from the fixed camera.
2. Crop the fixed ROI.
3. Run the bean/no-bean CNN classifier.
4. If beans are detected, calculate the mean grayscale value.
5. Log grayscale, temperature, time, and batch ID together.
6. Use the combined data for roast monitoring and future AI-assisted roast optimisation.

---

## Safety Note

This module is intended to support roast monitoring. It should not replace thermal safety checks, emergency stop behaviour, or electrical safety precautions in the main coffee roaster system.

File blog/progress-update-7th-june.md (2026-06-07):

# Smart Coffee Roaster – Progress Update
## 7 June 2026

---

# Introduction

Since the previous update, the project has progressed from early prototyping into a fully functional smart coffee roasting system.

The team has focused on integrating the core hardware, control system, and user interface required to perform automated coffee roasting. Multiple successful roasting tests have now been completed, allowing the team to evaluate system performance and begin refining the overall design.

The current system is capable of monitoring roast temperature, controlling airflow and heating, and executing roasting profiles through a dedicated user interface.

---

# Hardware Integration and Testing

Since the previous update, all ordered components have been received and integrated into the prototype system.

The team has successfully tested:

* Raspberry Pi 4 integration
* K-type thermocouple sensing
* Heater control through the SSR
* Fan motor control
* Power conversion hardware

---

# Airflow Development

Following the airflow issues identified during earlier testing, a new fan was designed and manufactured using PETG through 3D printing.

Testing showed improved bean movement within the roasting chamber, helping achieve more effective fluidisation during roasting.

The team has recorded videos of the roasting process to support testing and evaluation.

---

# Safety and Electrical Design

Progress has also been made on improving system safety.

The mains-powered sections of the system have now been enclosed to reduce exposure to high-voltage components. Work is ongoing to further improve enclosure of the remaining low-voltage electronics.

---

# Control System Development

Development of the roasting control system has continued significantly since the previous update.

Initial testing was performed using PID control. While functional, the team found that temperature overshoot could be reduced through alternative control methods.

As a result, the project has begun transitioning towards Model Predictive Control (MPC), which has shown improved temperature regulation during testing.

The current system is capable of:

* Monitoring roast temperature
* Controlling heater operation
* Controlling airflow
* Executing automated roast profiles

---

# User Interface Development

The user interface has continued to evolve and now provides greater control over the roasting process.

Current functionality includes:

* Real-time temperature graphing
* Roast temperature selection
* Preset roast profiles
* Start Roast control
* Stop & Cool control
* Emergency Stop functionality

Preset profiles currently correspond to different roast levels, allowing users to select their desired roast more easily.

---

# Current System Status

The project has now achieved its minimum viable functionality.

The current prototype is capable of:

* Roasting coffee beans successfully
* Monitoring temperature in real time
* Controlling heater output
* Controlling airflow
* Running roast profiles
* Cooling beans after roasting
* Providing user interaction through the graphical interface

AI functionality has not yet been implemented, as the current focus has been on establishing a stable and reliable roasting platform.

---

# Next Steps

The next phase of development is expected to include:

* Further enclosure improvements
* Addition of a second thermocouple for improved monitoring and control
* Integration of a dedicated display for the user interface
* Investigation of camera-based AI features
* Refinement of the roasting control algorithm

Future updates will focus on system refinement and AI-assisted roasting capabilities.

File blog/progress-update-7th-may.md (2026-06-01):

# Smart Coffee Roaster – Progress Update
## 7 May 2026

---

# Introduction

Our project focuses on developing an AI-enabled small batch coffee roasting machine that addresses sustainability and accessibility challenges within coffee roasting.

The project combines embedded systems, sensing, control engineering, and AI technologies to create a low-cost intelligent coffee roaster capable of producing consistent roast profiles while improving user experience and safety.

Our current concept is based around modifying a hot-air popcorn popper into a fluidised bed coffee roaster platform.

---

# Sustainability Motivation

Coffee roasting presents several sustainability challenges including:

- Energy consumption
- Waste from inconsistent roasting
- Limited accessibility to affordable roasting equipment
- Dependence on large-scale commercial roasting systems

Our goal is to explore how intelligent monitoring and control can improve roast consistency while reducing waste and improving accessibility.

---

# IBM Onboarding Progress

All team members have completed the following onboarding tasks:

- IBM Design Thinking for Academia badge
- Two IBM AI SkillsBuild badges

These activities helped establish a shared understanding of AI concepts, collaboration, and design thinking methodologies.

---

# Initial Technical Research

Our team researched DIY coffee roasting systems, particularly fluidised bed roasters based on popcorn poppers.

From this research, we identified several important engineering challenges:

- Maintaining stable temperature profiles
- Ensuring sufficient airflow for even roasting
- Preventing overheating
- Achieving roast repeatability
- Managing safe cooling after roasting
- Improving overall system safety

We also researched coffee roasting phases including:
- Drying phase
- Maillard reaction
- First crack
- Development phase
- Cooling phase

This highlighted the importance of sensing and closed-loop control.

---

# Early System Concept

## Proposed Sensing
- Bean temperature sensing
- Air temperature sensing
- Potential future airflow and power sensing

## Proposed Control
- Fan speed control
- Heater power control
- Roast profile tracking
- Cooling mode control

## Proposed AI Features
- Roast data logging
- Roast profile recommendations
- AI-assisted optimisation
- Future dashboard or analytics system

At this stage, the architecture is still evolving and may change during prototyping.

---

# MoSCoW Requirements

## Must Have
- The system must use a Raspberry Pi as the main controller.
- The system must measure real-time temperature using a K-type thermocouple and MAX6675 or MAX31855 module.
- The system must implement a PID control loop for thermal control.
- The system must control heater output using an SSR or MOSFET-based power electronic switching method.
- The system must provide basic fan or airflow operation to support bean agitation and safety.
- The system must include safety shutdown logic for dangerous conditions.
- The system must log roast data such as temperature, time, and heater output.
- The system must include a basic dashboard for live monitoring.
- The system must complete a functional demonstration roast or controlled heating test.
- The system must include a technical report and Git repository.

## Should Have
- The system should provide an internet-accessible remote dashboard.
- The system should provide a mobile application dashboard.
- The dashboard should include secure access control.
- The system should calculate and display Rate of Rise.
- The dashboard should display roast phase indicators such as drying, Maillard, and development.
- The system should support light, medium, and dark roast profiles.
- The project should show clear IBM Granite usage for code optimisation, testing, documentation, and analysis.
- The final report should include a reflection on how IBM SkillsBuild improved the development workflow.
- The project should include safety testing and documented fault responses.

## Could Have
- The system could include machine learning-based roast suggestions.
- The system could include automatic PID tuning support.
- The system could store data in a cloud database.
- The dashboard could include advanced graphs and comparison between roast curves.
- The system could store multiple bean profiles.
- The system could recommend future roast settings based on previous roast data.

## Won’t Have (For Now)
- The project will not build a commercial coffee roasting product.
- The project will not support large-batch roasting.
- The project will not include voice assistant control.
- The project will not create a fully automated machine learning roaster as a core requirement.
- The project will not build a complete carbon-emissions model.
- The project will not focus on advanced mechanical redesign unless time allows.
- The project will not depend on cloud infrastructure for the basic system to function.

---

# Current Planning and Procurement

Our team is currently preparing to purchase:
- A popcorn popper base system
- Temperature sensing components
- Control electronics
- Additional safety-related hardware

We are also evaluating:
- Sensor options
- Microcontroller platforms
- Safe power control approaches
- AI integration methods

---

# Next Steps

Our next development phase will include:

- Component procurement and breadboard testing of the sensor/control loop.
- Chassis modification and safety-critical wiring (AC side isolation).
- Software development (PID tuning and web dashboard implementation).

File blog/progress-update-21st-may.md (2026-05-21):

# Smart Coffee Roaster – Progress Update
## 21 May 2026

---

# Introduction

Since the previous update, the project has progressed from initial research and planning into early hardware prototyping and system testing.

Our team has focused on acquiring core components, investigating the popcorn popper platform, improving system safety, and beginning development of the control and software architecture required for the smart coffee roaster.

The current development approach is focused on first creating a minimum viable roasting system before gradually integrating more advanced features such as AI-assisted optimisation.

---

# Hardware Procurement and Components

A range of components have now been ordered or received to support early prototyping and testing.

## Components Ordered
- Popcorn popper
- Solid State Relay (SSR)
- K-type thermocouple
- MAX31855 thermocouple interface
- AC to DC converters
- WAGO connectors
- DPST switch
- Cabling and cable glands
- Enclosures
- Motor
- Heatsink
- Spade crimp connectors
- 3mm acrylic
- MOSFETs (IRF530N)
- Diodes (IN5408)
- BJTs (2N3904)
- Zener diodes

In addition, IBM has provided the team with a Raspberry Pi 4 platform to support software, control, and AI integration.

---

# Popcorn Popper Investigation and Testing

The popcorn popper has now been opened, inspected, and tested using coffee beans.

Initial testing showed that the beans did not circulate effectively enough for reliable fluidised bed roasting. As a result, the team has started developing an improved fan system, including the design and 3D printing of a new fan component to improve airflow and bean movement.

This testing phase helped identify several practical engineering considerations relating to airflow, thermal behaviour, and roasting consistency.

---

# Safety and Electrical Design

Safety has been an important consideration during early prototyping, particularly due to the use of mains.

The team identified risks associated with exposed wiring and AC mains connections during initial testing. To address this, additional safety-focused hardware was purchased, including:
- Protective enclosures
- Cable glands
- Improved cable management hardware

The current design approach aims to isolate and cover mains AC wiring while allowing safer access to lower-voltage sections of the system for development and testing purposes.

---

# Early Control System Development

Work has started on developing the control architecture for the roaster.

Current investigations and tests include:

- Initial closed-loop PID control experiments
- Heat gun testing as a safer substitute for the final heater during early development
- Observation of control output signals using an oscilloscope
- Early motor control testing for airflow regulation
- Testing of bean spinning and airflow mechanisms

These early experiments are helping the team better understand the thermal and dynamic behaviour of the system before integrating the final heating solution.

At this stage, AI functionality has not yet been implemented, as the current priority is establishing a stable and functional minimum-requirement roasting system.

---

# Software and Repository Development

The project repository has also evolved as development progresses. Its structure is intended to support future integration between hardware control, backend processing, frontend monitoring interfaces, and project documentation.

The team has also started testing an early user interface website as part of future monitoring and control development.

---

# Next Steps

The next phase of development is expected to include:

- Continued airflow and fan optimisation
- Integration of thermocouple temperature sensing
- Further motor control testing
- Initial heater control integration
- Expansion of the software and frontend systems
- Development of the first complete prototype circuit

Future updates will document the transition from early prototyping into integrated system testing.

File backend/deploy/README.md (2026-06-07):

# Deploying the Coffee Roaster on Raspberry Pi

This folder contains scripts to run the roast API (`api/main.py`) as a **systemd** service on boot. The service starts the WebSocket API on port **8000** and the SPI LCD dashboard in the same process (when `HARDWARE_MODE=pi`).

**These files live in your git repo.** Nothing is installed on the Pi until you copy or pull the code there and run the install script.

## Files in this folder

| File | Purpose |
|---|---|
| `coffee-roaster.service` | systemd unit template |
| `install-service.sh` | Install, enable, and start the service |
| `uninstall-service.sh` | Stop, disable, and remove the service |
| `cleanup-services.sh` | Audit + stop/disable service, kill stray API processes |

The install script must be run from the folder that contains **`api/`** and **`deploy/`**. Two layouts work:

**Flat (common on the Pi)** — `CoffeeController` is the app root:

```
~/Desktop/CoffeeController/
├── .venv/
├── api/
├── deploy/
├── hardware/
└── requirements.txt
```

**Nested (git repo)** — `backend/` is the app root, venv one level up:

```
~/Desktop/CoffeeController/
├── .venv/
└── backend/
    ├── api/
    ├── deploy/
    └── requirements.txt
```

## Prerequisites

On the Pi, before installing the service:

1. **Clone or sync the repo** so `api/main.py` and `requirements.txt` are present.
2. **Python venv** with dependencies installed:

   Flat layout:

   ```bash
   cd ~/Desktop/CoffeeController
   python3 -m venv .venv
   .venv/bin/pip install -r requirements.txt
   ```

   Nested layout:

   ```bash
   cd ~/Desktop/CoffeeController
   python3 -m venv .venv
   .venv/bin/pip install -r backend/requirements.txt
   ```

   `install-service.sh` picks `.venv/bin/python3` next to `api/` or in the parent folder.

3. **SPI enabled** (thermocouple on SPI0, LCD on SPI1):

   ```bash
   sudo raspi-config   # Interface Options → SPI → Enable
   sudo reboot
   ls /dev/spidev*
   ```

4. **GPIO/SPI permissions** for the service user (e.g. `coffee`):

   ```bash
   sudo usermod -aG gpio,spi coffee
   ```

   Log out and back in (or reboot) after adding groups.

5. **Smoke-test manually once** before enabling boot startup:

   ```bash
   cd ~/Desktop/CoffeeController    # folder with api/
   .venv/bin/python3 api/main.py
   ```

   - Dashboard WebSocket: `ws://127.0.0.1:8000/ws/telemetry`
   - LCD wiring: see `docs/lcd_st7796_test.md`

   Press Ctrl+C when satisfied. Do **not** run `hardware_test.py` at the same time — it uses port **8001** and conflicts on GPIO.

## Install (boot on startup)

From the app directory on the Pi (contains `api/` and `deploy/`):

```bash
cd ~/Desktop/CoffeeController
chmod +x deploy/install-service.sh
sudo ./deploy/install-service.sh
```

The script:

- Writes `/etc/systemd/system/coffee-roaster.service`
- Sets `User` / `Group` to whoever owns the `backend/` folder (e.g. `coffee`, not only `pi`)
- Sets `WorkingDirectory` to the real `backend/` path
- Sets `ExecStart` to `CoffeeController/.venv/bin/python3` when that venv exists
- Runs `systemctl enable` and `systemctl restart`

### Customise the service

Edit `deploy/coffee-roaster.service` **before** installing if needed:

| Setting | Default | Notes |
|---|---|---|
| `User` / `Group` | owner of `backend/` | Set automatically by `install-service.sh` |
| `WorkingDirectory` | `.../CoffeeController/backend` | Overwritten by `install-service.sh` |
| `ExecStart` | `.../CoffeeController/.venv/bin/python3 api/main.py` | Auto-detected; falls back to `/usr/bin/python3` if `.venv` is missing |
| `Environment` | `PYTHONUNBUFFERED=1` | Add `ROASTER_LCD=0` to disable LCD, or `ROASTER_HARDWARE_MODE=mock` for testing |

Example — LCD off but API on boot:

```ini
Environment=PYTHONUNBUFFERED=1 ROASTER_LCD=0
```

Re-run `sudo ./deploy/install-service.sh` after editing the template.

## Verify deployment

```bash
sudo systemctl status coffee-roaster
journalctl -u coffee-roaster -f
```

Healthy signs:

- `Active: active (running)`
- Logs show Uvicorn listening on `0.0.0.0:8000`
- No repeated crash/restart loop (`Restart=on-failure` with 5 s delay)

Useful commands:

```bash
sudo systemctl restart coffee-roaster   # after code or config changes
sudo systemctl stop coffee-roaster      # stop until next boot (if enabled)
sudo systemctl disable coffee-roaster   # stop boot startup, keep unit file
```

After pulling new code, restart the service:

```bash
cd ~/Desktop/CoffeeController
git pull
.venv/bin/pip install -r backend/requirements.txt    # if dependencies changed
sudo systemctl restart coffee-roaster
```

## Clear deployment (uninstall service)

If things are broken and you want a full reset (stop service, remove unit, kill stray `main.py`):

```bash
cd ~/Desktop/CoffeeController
chmod +x deploy/cleanup-services.sh
sudo ./deploy/cleanup-services.sh
```

To only remove the systemd unit (no process audit):

```bash
cd ~/Desktop/CoffeeController
chmod +x deploy/uninstall-service.sh
sudo ./deploy/uninstall-service.sh
```

This stops the service, disables it, removes `/etc/systemd/system/coffee-roaster.service`, and reloads systemd. **It does not delete your repo, logs, or Python packages.**

### Manual uninstall

If you prefer not to use the script:

```bash
sudo systemctl stop coffee-roaster
sudo systemctl disable coffee-roaster
sudo rm -f /etc/systemd/system/coffee-roaster.service
sudo systemctl daemon-reload
sudo systemctl reset-failed coffee-roaster 2>/dev/null || true
```

Confirm removal:

```bash
systemctl status coffee-roaster   # should report "could not be found"
```

### Stop a manual run (no systemd)

If you started the API by hand (`python3 api/main.py`) and never installed the service:

- Press **Ctrl+C** in that terminal, or
- `pkill -f "api/main.py"` (only if no other Python job should match)

### Optional cleanup (not done by uninstall)

| What | Command / action |
|---|---|
| Roast CSV logs | `rm -rf backend/logs/*` — only if you intend to wipe history |
| Python venv | Remove the venv directory you created |
| SPI / gpio groups | `sudo gpasswd -d pi spi` etc. — rarely needed |

## Troubleshooting

### `env: 'bash\r': No such file or directory`

The deploy scripts have **Windows line endings (CRLF)**. Fix on the Pi:

```bash
cd ~/Desktop/CoffeeController
sed -i 's/\r$//' deploy/*.sh
chmod +x deploy/*.sh
sudo ./deploy/install-service.sh
```

(`dos2unix deploy/*.sh` also works if installed.) The repo uses `.gitattributes` to keep `*.sh` as LF — re-clone or `git pull` after that file is present.

### Unit not found

The service was never installed. Run `sudo ./deploy/install-service.sh`.

### `status=217/USER` — “Failed to determine user credentials”

The unit still has `User=pi` but your login is different (e.g. `coffee`). Re-install from **`backend/`**, not the project root:

```bash
cd ~/Desktop/CoffeeController/backend
sudo ./deploy/install-service.sh
```

Confirm the installed unit:

```bash
grep -E '^(User|Group|ExecStart|WorkingDirectory)=' /etc/systemd/system/coffee-roaster.service
```

You should see `User=coffee`, `.venv/bin/python3`, and `WorkingDirectory=.../backend`.

Add GPIO/SPI for that user:

```bash
sudo usermod -aG gpio,spi coffee
```

Reboot or re-login after `usermod`.

### `ModuleNotFoundError: No module named 'fastapi'`

The service is using the wrong Python (system `/usr/bin/python3` instead of `.venv`). Fix deps, then re-install:

```bash
cd ~/Desktop/CoffeeController
.venv/bin/pip install -r requirements.txt
sudo ./deploy/install-service.sh
```

Check the unit uses the venv:

```bash
grep ExecStart= /etc/systemd/system/coffee-roaster.service
# should be: .../CoffeeController/.venv/bin/python3 api/main.py
```

### Service starts then exits (restart loop)

```bash
journalctl -u coffee-roaster -n 50 --no-pager
```

Common causes:

- Wrong `WorkingDirectory` or missing `requirements.txt` packages
- GPIO/SPI permission denied — check `gpio,spi` group membership
- Port 8000 already in use — stop a leftover `main.py` or other process
- Import errors after a partial git sync — pull full `backend/` tree

### WebSocket 403 on `/ws/telemetry`

Port 8000 is serving the **bench** API or another app. Only `api/main.py` should own 8000. Bench uses `hardware_test.py` on **8001**.

### LCD blank but API works

- Run LCD smoke test: `../.venv/bin/python3 hardware/display/st7796.py` (from `backend/`)
- Check SPI1 overlay and wiring: `docs/lcd_st7796_test.md`
- Disable LCD temporarily: `ROASTER_LCD=0` in the service `Environment` line

### Two APIs at once

Never run `main.py` and `hardware_test.py` together on the Pi — shared GPIO will conflict.

## Related docs

- Backend overview: `../README.md`
- LCD hardware: `../docs/lcd_st7796_test.md`
- Bench / dev testing: `../api/hardware_test.py` (port 8001, not for production boot)

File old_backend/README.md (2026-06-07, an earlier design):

# Smart Coffee Roaster — Backend

Python backend: **WebSocket API**, **GPIO hardware control**, **roast logging**, and **ML-ready CSV data**.

## Overview

```
Nuxt dashboard  →  ws://<pi>:8000/ws/telemetry
                      ↓
              api/main.py (FastAPI)
                      ↓
         hardware/controller.py (RoasterController)
                      ↓
    thermocouple · heater · motor · MPC/PID · roast_logger
```

## Two APIs (do not run both on the Pi at once)

| | Roast | Hardware bench |
|--|---|---|
| **Run** | `python api/main.py` | `python api/hardware_test.py` |
| **Port** | 8000 | 8001 |
| **WebSocket** | `/ws/telemetry` | `/ws/bench` |
| **Code** | `hardware/controller.py` | `hardware/hardware_test_bench.py` |

Bench UI: frontend `/hardware-test` — fan, heater, PID/MPC tuning, E-stop.

## Quick start (Raspberry Pi)

Venv lives at **`CoffeeController/.venv`** (project root, sibling of `backend/`).

```bash
cd ~/Desktop/CoffeeController
python3 -m venv .venv
.venv/bin/pip install -r backend/requirements.txt
cd backend
../.venv/bin/python3 api/main.py   # roast API + LCD on the Pi (default)
```

Dashboard: `ws://127.0.0.1:8000/ws/telemetry`

LCD is **on by default** when `HARDWARE_MODE=pi` in `config.py`. Disable with `ROASTER_LCD=0` or force on with `--lcd`.

### Boot on startup (Raspberry Pi)

Full guide (install, update, uninstall): **`deploy/README.md`**.

```bash
cd backend
chmod +x deploy/install-service.sh
sudo ./deploy/install-service.sh
```

Remove boot deployment: `sudo ./deploy/uninstall-service.sh` (see `deploy/README.md`).

Standalone LCD only: `python hardware/display/lcd.py`.

**Local UI without GPIO:** `python api/mock_ui_server.py` (stdlib only, port 8000).

## WebSocket — roast API

### Commands (client → server)

| Action | JSON |
|---|---|
| Start roast | `{"action":"START_ROAST","profile_id":"medium"}` |
| Stop & cool | `{"action":"STOP_ROAST"}` |
| Resume | `{"action":"RESUME_ROAST"}` |
| Finish now | `{"action":"FINISH_ROAST"}` |
| Emergency | `{"action":"E_STOP"}` |
| State sync | `{"action":"GET_STATE"}` |

### Telemetry (server → client, ~2 Hz)

```json
{
  "type": "telemetry",
  "timestamp": 42.5,
  "temp": 187.3,
  "target": 210.0,
  "setpoint": 185.2,
  "ramp_midpoint_min": 2.0,
  "ramp_steepness": 1.0,
  "heater_pwm": 65,
  "fan_pwm": 100,
  "state": "ROASTING",
  "heater_halted": false,
  "sensor_fault": null,
  "can_resume": false,
  "test_spin": false
}
```

RoR is still written to roast CSV logs for ML; it is not sent on the WebSocket (dashboard does not display it).

## State machine

| State | Meaning |
|---|---|
| `IDLE` | Off |
| `PREHEAT` | Warming toward profile target |
| `ROASTING` | At/above preheat threshold (150 °C) |
| `COOLING` | User stopped; fan on until cool |
| `ERROR` | Over-temp (>250 °C) |

- `START_ROAST` → `PREHEAT`
- Temp ≥ **150 °C** → `ROASTING`
- `STOP_ROAST` → `COOLING`
- Temp ≤ **33 °C** in `COOLING` → `IDLE`
- Temp > **250 °C** → `ERROR`

## Control

- **Heater:** time-proportional relay (`HEATER_CONTROL_WINDOW_S = 1.0` s). Duty from `MPCController` or `PIDController` — set `HEATER_CONTROLLER` in `config.py`.
- **Setpoint ramp:** sigmoid from bean start temp to profile target (`hardware/control/roast_ramp.py`).
- **Overshoot:** heater forced to 0% when temp > target + **15 °C**.
- **Fan:** on during preheat/roast/cool; off at idle after cool-down.

## Hardware modules

| File | Role |
|---|---|
| `devices/thermocouple.py` | MAX31855, single probe, raw reading |
| `devices/heater.py` | SSR relay, time-proportional `apply_output()` |
| `devices/motor.py` | Fan PWM (GPIO 12) |
| `control/heater_control.py` | Factory: MPC or PID |
| `control/mpc.py` / `control/pid.py` | Heater duty 0–100% |
| `control/roast_ramp.py` | Sigmoid setpoint curve |
| `roast_logger.py` | CSV + JSON metadata |
| `hardware_test_bench.py` | Bench-only GPIO test harness |
| `display/st7796.py` / `display/lcd.py` | SPI driver + live WebSocket dashboard |

## Configuration (`config.py`)

| Setting | Value |
|---|---|
| `HEATER_GPIO` | 23 |
| `THERMOCOUPLE_CS_GPIO` | 7 (SPI0 CE1) |
| `FAN_PWM_GPIO` | 12 |
| `COOL_DOWN_TEMP_C` | 33 |
| `HEATER_CONTROLLER` | `"mpc"` or `"pid"` |
| `BENCH_DEFAULT_CONTROLLER` | bench startup mode |

Profiles: `GET /api/profiles` — same data as `ROAST_PROFILES` in config.

## Data logging

- `logs/roast_<id>.csv` — time series
- `logs/roast_<id>_meta.json` — session metadata
- `logs/roasts_index.csv` — index

CSV includes `ror_c_per_min` for ML. Examples: `examples/roast_data_formats.json`.

HTTP: `GET /api/roasts`, `GET /api/roasts/{roast_id}`.

## Project layout

```
backend/
├── config.py
├── api/
│   ├── main.py              # Roast API (8000)
│   ├── hardware_test.py     # Bench API (8001)
│   └── mock_ui_server.py    # Dev mock (no GPIO)
├── hardware/
│   ├── controller.py           # Roast orchestration
│   ├── hardware_test_bench.py  # Bench GPIO harness
│   ├── roast_logger.py
│   ├── devices/                # thermocouple, heater, motor
│   ├── control/                # pid, mpc, heater_control, roast_ramp
│   └── display/                # st7796.py (driver), lcd.py (dashboard)
├── deploy/                     # systemd install + uninstall scripts
├── docs/lcd_st7796_test.md
├── examples/roast_data_formats.json
└── requirements.txt
```

## GPIO pinout

Full wiring table (physical pins + BCM GPIO): **`docs/gpio_pinout.md`**.

## LCD

See `docs/lcd_st7796_test.md`. LCD code lives in `hardware/display/`. LCD uses **SPI1** (CS GPIO 17); thermocouple stays on **SPI0**.

## Troubleshooting

### `/dev/spidev0.0` missing

```bash
sudo raspi-config   # Interface Options → SPI → Enable
sudo reboot
ls /dev/spidev*
```

Thermocouple CS: GPIO **7** (`THERMOCOUPLE_CS_GPIO`). Add user to `spi,gpio` if permission errors.

### WebSocket 403 on `/ws/telemetry`

Wrong server on port 8000 — run `main.py`, not `hardware_test.py`.

### Thermocouple fault

Fix probe wiring before enabling the heater.

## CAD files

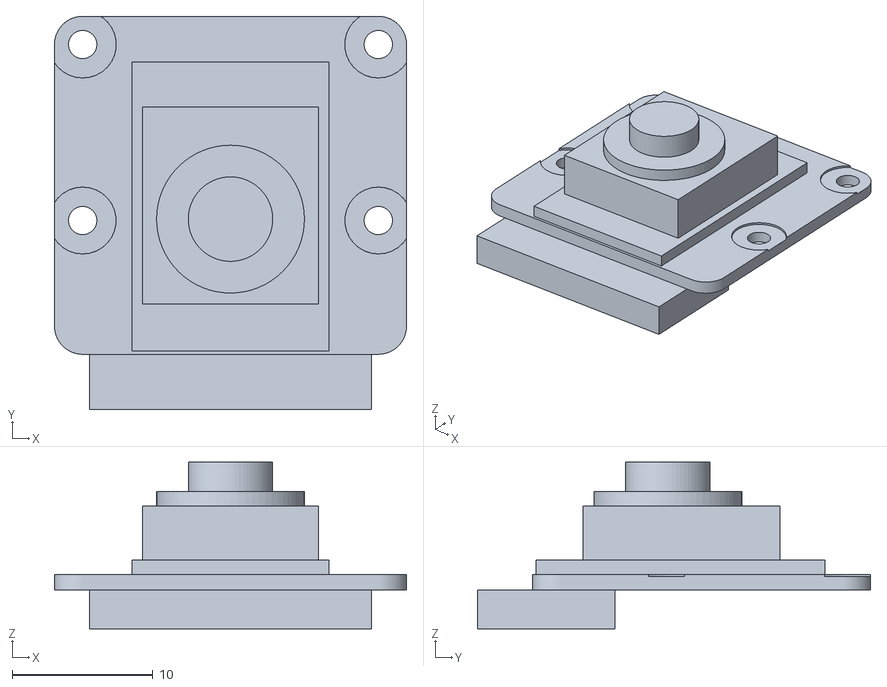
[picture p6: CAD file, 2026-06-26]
3D_prints/Raspberry PI AI Camera.stl
25.0 x 27.9 x 11.8

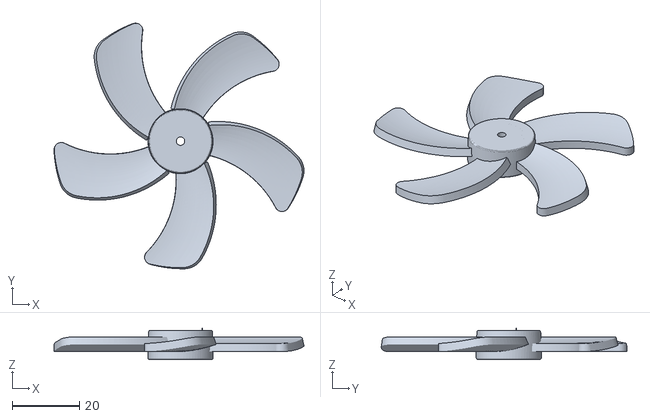
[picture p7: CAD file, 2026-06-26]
3D_prints/axial fan v4.stl
74.1 x 72.8 x 9.23

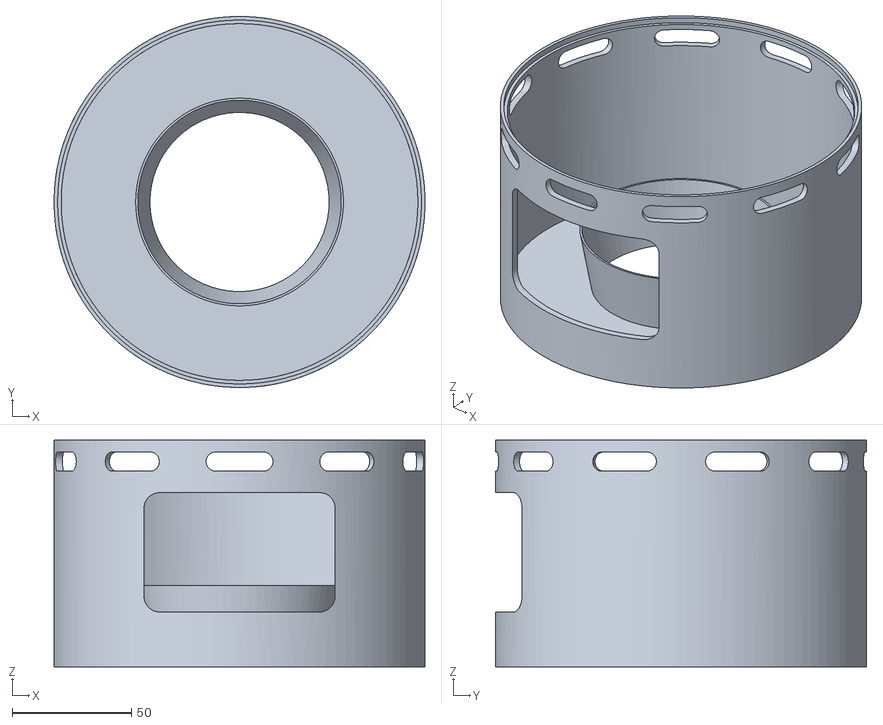
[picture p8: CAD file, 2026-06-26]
3D_prints/Mount_Base_New.stl
155.4 x 155.4 x 95.0

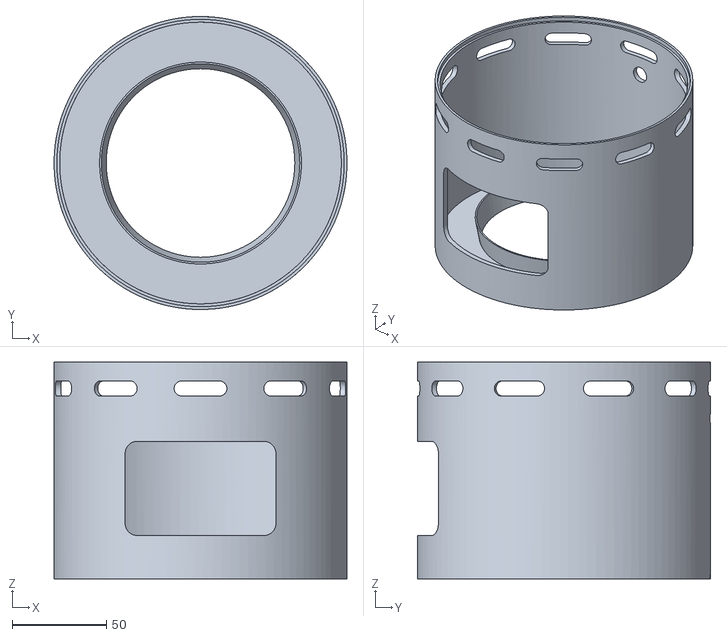
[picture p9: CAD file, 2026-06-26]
3D_prints/Top_Base.stl
155.4 x 155.4 x 115.0

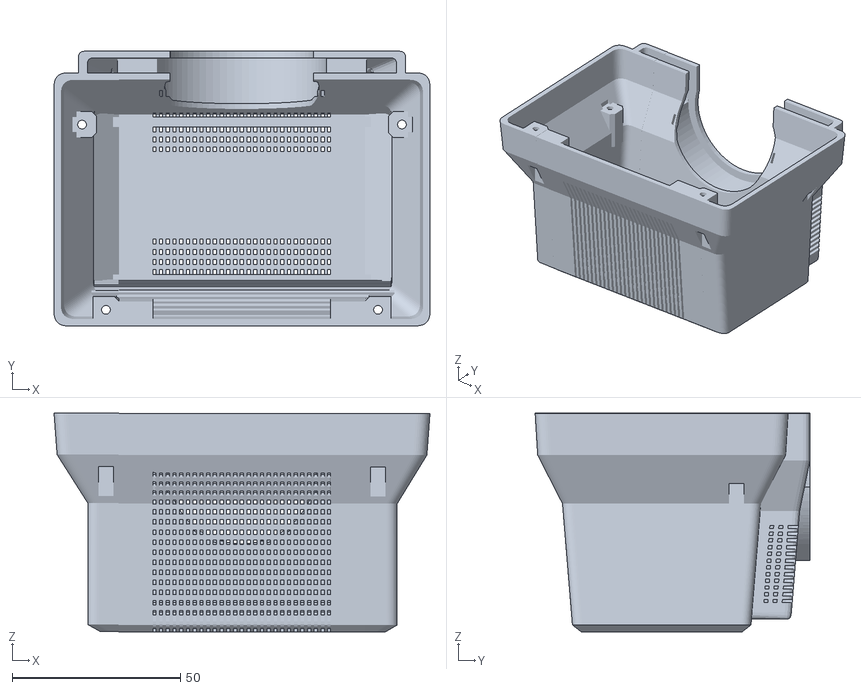
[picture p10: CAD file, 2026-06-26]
3D_prints/MONITOR_BACK.stl
111.7 x 81.6 x 65.0

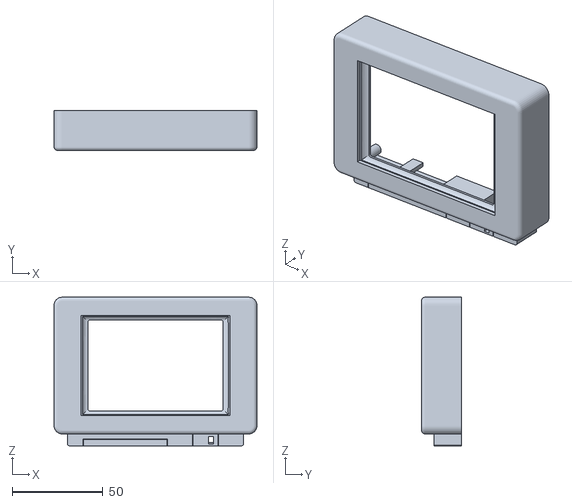
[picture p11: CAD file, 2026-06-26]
3D_prints/MONITOR_FRONT.stl
111.7 x 22.0 x 81.8

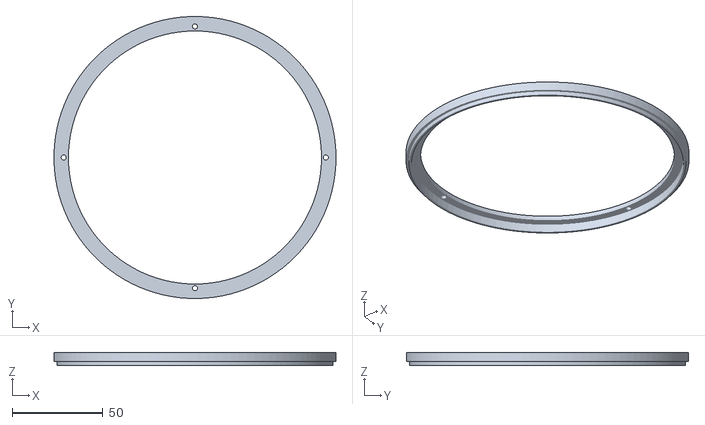
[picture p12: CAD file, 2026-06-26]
3D_prints/Mount Top.stl
155.4 x 155.4 x 7.00

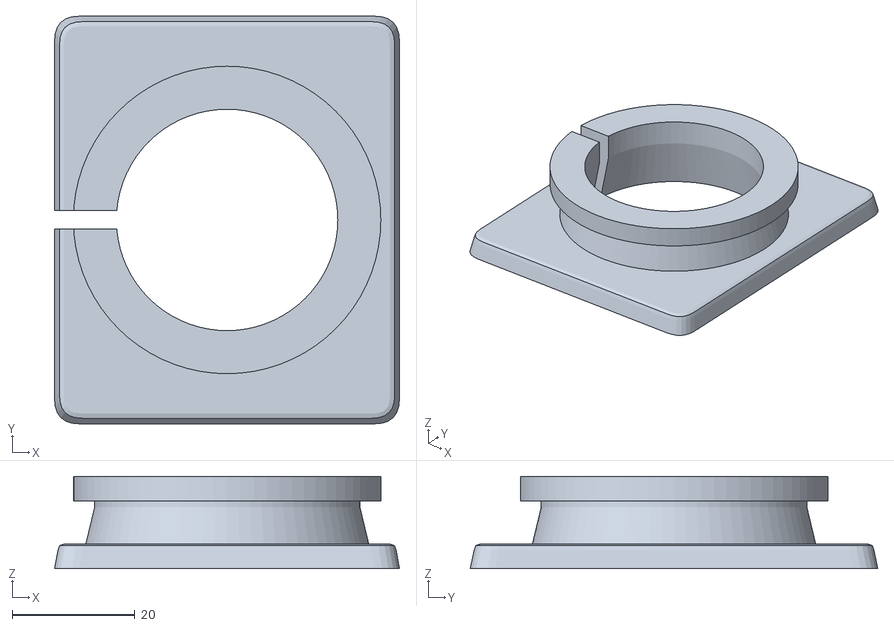
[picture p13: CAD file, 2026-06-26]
3D_prints/monitor_base v1.stl
56.1 x 66.3 x 15.0

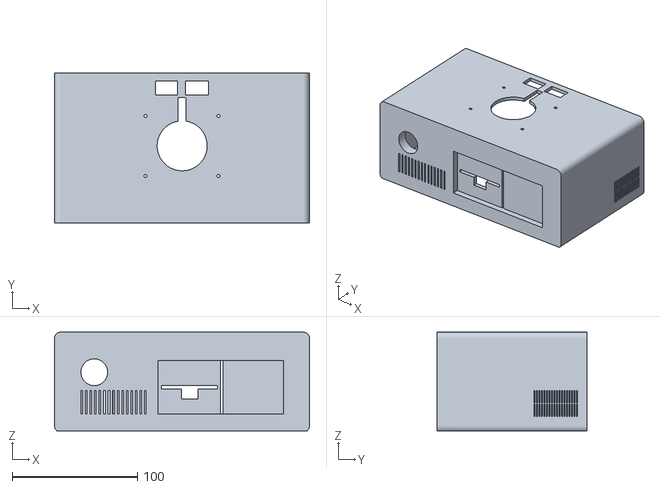
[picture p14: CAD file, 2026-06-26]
3D_prints/DESKTOP_COVER_final.stl
204.0 x 119.7 x 79.0

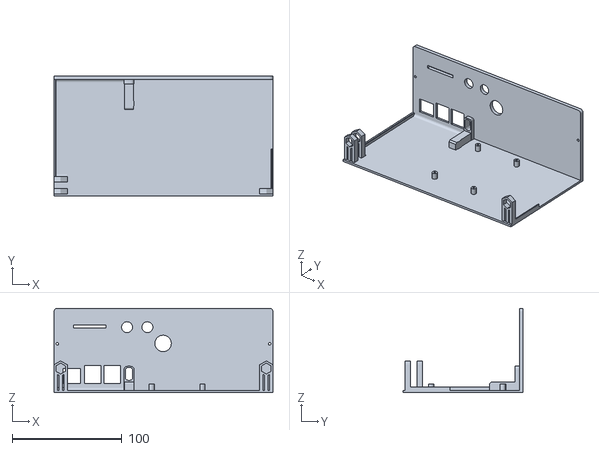
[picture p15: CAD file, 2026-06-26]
3D_prints/DESKTOP_BASE 2.stl
200.0 x 110.0 x 77.0

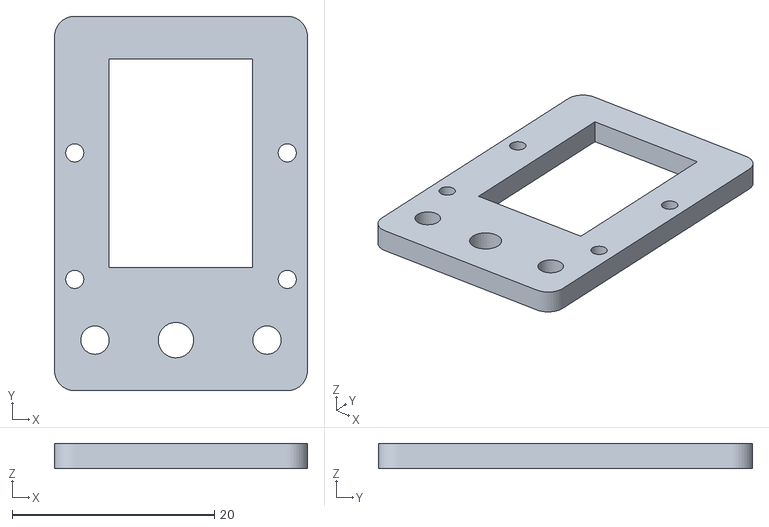
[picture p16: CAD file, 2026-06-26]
3D_prints/Mount_Cam.stl
25.0 x 37.0 x 2.50

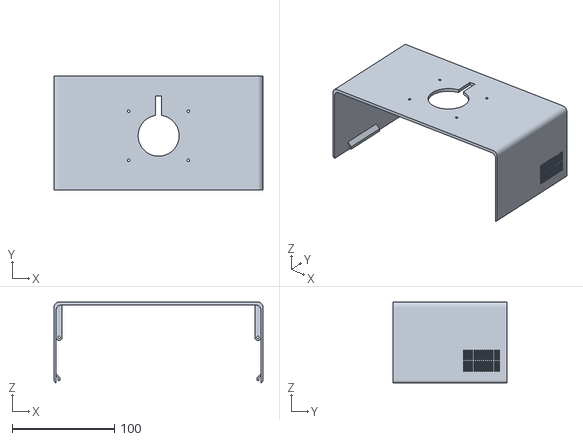
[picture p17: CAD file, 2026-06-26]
3D_prints/DESKTOP_COVER_2.stl
204.0 x 111.0 x 79.0

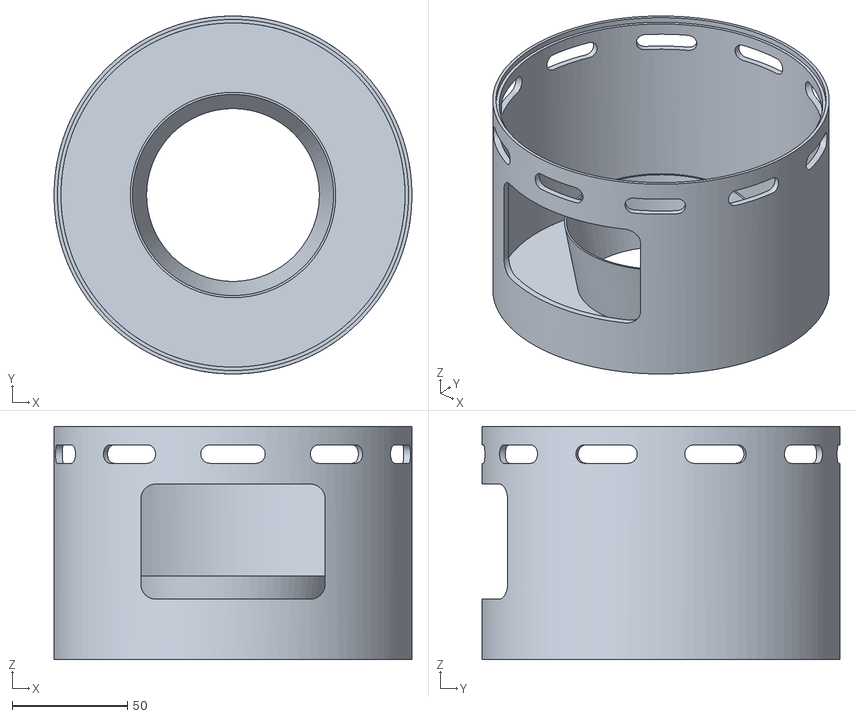
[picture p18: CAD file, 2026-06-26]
3D_prints/Mount_Base.stl
155.4 x 155.4 x 101.2

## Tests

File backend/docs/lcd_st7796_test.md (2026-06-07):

# ST7796 SPI LCD Test

**Full roaster pinout (heater, fan, thermocouple, LCD):** `gpio_pinout.md`.

This note is for the LCDWiki 3.5 inch IPS SPI Module using the ST7796 driver:
https://www.lcdwiki.com/zh/3.5inch_IPS_SPI_Module_ST7796

The project already uses Raspberry Pi SPI0 for the MAX31855 thermocouple:

- SPI0 SCLK: BCM GPIO 11, physical pin 23
- SPI0 MISO: BCM GPIO 9, physical pin 21
- SPI0 MOSI: BCM GPIO 10, physical pin 19
- Thermocouple CS: BCM GPIO 7, physical pin 26, SPI0 CE1

Use SPI1 for the LCD smoke test so high-volume image transfers do not share the
thermocouple SPI0 bus. SPI1 normally puts CE0 on BCM GPIO 18, but this project
already uses GPIO 23 for the heater SSR. Remap SPI1 CS to BCM GPIO 17 before
running the test.

## Pins Already Used By The Roaster

| Function | BCM GPIO | Physical pin |
| --- | ---: | ---: |
| Heater SSR | GPIO 23 | 16 |
| Fan PWM | GPIO 12 | 32 |
| MAX31855 CS | GPIO 7 / CE1 | 26 |
| SPI0 MOSI | GPIO 10 | 19 |
| SPI0 MISO | GPIO 9 | 21 |
| SPI0 SCLK | GPIO 11 | 23 |
| SPI1 default CE0, do not use | GPIO 18 | 12 | (heater is on GPIO 23) |

## LCD Wiring

Power the LCD from the Raspberry Pi 3.3 V rail for the first test unless your
specific module documentation says its VCC pin must use 5 V. Keep all SPI and
control signals at 3.3 V logic.

The LCD test script uses `/dev/spidev1.0` and manually drives the LCD CS pin on
BCM GPIO 17. The default display orientation is landscape, rotated 90 degrees
clockwise from the original portrait wiring.

| LCD pin | Raspberry Pi signal | BCM GPIO | Physical pin | Notes |
| --- | --- | ---: | ---: | --- |
| VCC | 3.3 V | - | 1 or 17 | Module power |
| GND | GND | - | 6, 9, 14, 20, 25, 30, 34, or 39 | Common ground |
| CS / LCD_CS | SPI1 CS remapped | GPIO 17 | 11 | Avoids SSR GPIO 18 |
| RESET / RST | LCD reset | GPIO 24 | 18 | Free GPIO |
| DC / RS | Data/command | GPIO 25 | 22 | Free GPIO |
| SDI / MOSI | SPI1 MOSI | GPIO 20 | 38 | Dedicated LCD SPI bus |
| SCK / SCLK | SPI1 SCLK | GPIO 21 | 40 | Dedicated LCD SPI bus |
| LED / BL | Backlight enable | GPIO 22 | 15 | Driven high for test |
| SDO / MISO | SPI1 MISO | GPIO 19 | 35 | Optional for LCD-only test |
| T_CLK, T_CS, T_DIN, T_DO, T_IRQ | Not connected | - | - | Touch ignored |
| SD_CS, SD_MOSI, SD_MISO, SD_SCK | Not connected | - | - | SD slot ignored |

## Raspberry Pi Setup

Enable SPI and add the SPI1 overlay. On Raspberry Pi OS Bookworm, edit:

```bash
sudo nano /boot/firmware/config.txt
```

On older Raspberry Pi OS releases, the file may be `/boot/config.txt` instead.
Add these lines:

```text
dtparam=spi=on
dtoverlay=spi1-1cs,cs0_pin=17
```

Do not use plain `dtoverlay=spi1-1cs` for this project, because its default CE0
pin is GPIO 18 (conflicts if reused). Heater SSR is on GPIO 23. Reboot after
changing the config:

```bash
sudo reboot
```

After reboot, check that SPI1 is available:

```bash
ls /dev/spidev1.0
```

If that file does not exist, the Python script will fail before talking to the
LCD. Check all visible SPI device nodes:

```bash
ls -l /dev/spidev*
```

Also check that the overlay line is in the active boot config and is not
commented out with `#`:

```bash
grep -n "spi" /boot/firmware/config.txt
```

If `/boot/firmware/config.txt` does not exist on your Raspberry Pi OS image,
use `/boot/config.txt` instead.

Install/update the backend dependencies:

```bash
cd backend
python -m pip install -r requirements.txt
```

Run the LCD smoke test from the repository root:

```bash
python backend/hardware/display/st7796.py
```

You should see a full-screen 480 x 320 landscape color test card with a border
and center cross.
Leave the main roasting backend stopped for this first test. The LCD uses SPI1,
while the MAX31855 thermocouple stays on SPI0.

Optional image test:

```bash
python backend/hardware/display/st7796.py --image path/to/test.jpg
```

If you need to compare orientations:

```bash
python backend/hardware/display/st7796.py --rotation 0
python backend/hardware/display/st7796.py --rotation 90
python backend/hardware/display/st7796.py --rotation 180
python backend/hardware/display/st7796.py --rotation 270
```

## Runtime LCD Dashboard

After the smoke test works, the LCD can run as a small realtime dashboard. It
does not read the thermocouple or control GPIO directly. Instead, it connects to
the existing backend WebSocket and displays the same kind of telemetry used by
the web frontend: temperature, target/setpoint, heater %, roast state, and a
planned-vs-live temperature chart.

**Coupled (recommended on the Pi)** — LCD starts and stops with the API:

```bash
python backend/api/main.py --lcd
# bench: python backend/api/hardware_test.py --lcd
# or set ROASTER_LCD=1 in the environment
```

**Standalone** — separate process (must start the API first):

```bash
python backend/api/main.py
python backend/hardware/display/lcd.py
# bench: python backend/hardware/display/lcd.py --mode bench
```

The default dashboard WebSocket URLs are:

| Mode | WebSocket URL |
| --- | --- |
| Roast | `ws://127.0.0.1:8000/ws/telemetry` |
| Bench | `ws://127.0.0.1:8001/ws/bench` |

Override the URL if the backend is on another host:

```bash
python backend/hardware/display/lcd.py --ws-url ws://10.64.26.141:8000/ws/telemetry
```

If the dashboard is upside down or rotated the wrong way, change the rotation:

```bash
python backend/hardware/display/lcd.py --rotation 270
```

If the screen stays white or black:

- Check that SPI1 is enabled and `/dev/spidev1.0` exists.
- Check that LCD `CS` is on physical pin 11, not physical pin 12.
- Check that `dtoverlay=spi1-1cs,cs0_pin=17` is in the active boot config.
- If Python raises `FileNotFoundError` or says it cannot find `/dev/spidev1.0`,
  fix the SPI1 overlay first; it is not an LCD wiring problem yet.
- Try a slower SPI clock: `python backend/hardware/display/st7796.py --speed 8000000`.
- For the dashboard, try: `python backend/hardware/display/lcd.py --speed 8000000`.
- If colors look swapped, the LCD works; the `MADCTL` color-order byte in the
  script may need changing for that exact panel revision.

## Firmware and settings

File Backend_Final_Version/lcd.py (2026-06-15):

"""
Live LCD dashboard — WebSocket client + Pillow UI rendered over SPI.

Standalone:
    python backend/hardware/display/lcd.py

Coupled to the API (LCD starts/stops with the server):
    python backend/api/main.py --lcd
    python backend/api/hardware_test.py --lcd
"""

import argparse
from collections import deque
from dataclasses import dataclass, field
import json
import math
import threading
import time

try:
    from PIL import Image, ImageDraw, ImageFont
except ImportError as exc:
    raise SystemExit("LCD dashboard needs Pillow. Try: pip install Pillow") from exc

try:
    from websocket import (
        WebSocketConnectionClosedException,
        WebSocketTimeoutException,
        create_connection,
    )
except ImportError as exc:
    raise SystemExit(
        "LCD dashboard needs websocket-client. Try: pip install websocket-client"
    ) from exc

class cfg:
    LCD_FPS = 2.0
    LCD_RECONNECT_DELAY_S = 2.0
    LCD_ENABLED = True


def effective_setpoint(start_temp_c, final_target_c, elapsed_s, midpoint_min, steepness=1.0):
    start = float(start_temp_c)
    target = float(final_target_c)
    midpoint_min = float(midpoint_min)
    steepness = float(steepness)

    if target <= start:
        return target

    t_min = max(0.0, float(elapsed_s)) / 60.0

    raw_zero = (target - start) / (1.0 + math.exp(-steepness * (0.0 - midpoint_min))) + start
    raw_now = (target - start) / (1.0 + math.exp(-steepness * (t_min - midpoint_min))) + start

    setpoint = start + ((raw_now - raw_zero) / (target - raw_zero)) * (target - start)

    return min(setpoint, target)


from st7796 import (
    LCD_BACKLIGHT_BRIGHTNESS,
    LCD_CS,
    LCD_PIXEL_BRIGHTNESS,
    SPI_BUS,
    SPI_DEVICE,
    ST7796Display,
    image_to_rgb565,
)


DEFAULT_WS_URLS = {
    "roast": "ws://127.0.0.1:8000/ws/telemetry",
    "bench": "ws://127.0.0.1:8001/ws/bench",
}

BG = (30, 28, 24)
CARD = (42, 38, 32)
CARD_ALT = (34, 32, 28)
BORDER = (72, 62, 50)
TEXT = (255, 252, 245)
MUTED = (178, 168, 152)
DIM = (118, 108, 94)
GOLD = (212, 162, 78)
AMBER = (245, 158, 11)
ORANGE = (249, 115, 22)
EMERALD = (52, 211, 153)
SKY = (56, 189, 248)
RED = (239, 68, 68)
PROFILE_MAX = (110, 105, 100)
CHART_BG = (20, 18, 16)

TEMP_MIN = 20
TEMP_MAX = 230

STATE_LABELS = {
    "IDLE": "Idle",
    "PREHEAT": "Preheating",
    "ROASTING": "Roasting",
    "COOLING": "Cooling",
    "ERROR": "Error",
    "BENCH": "Bench",
    "BENCH IDLE": "Bench idle",
}


@dataclass
class DashboardState:
    connected: bool = False
    mode: str = "roast"
    temp: float | None = None
    target: float | None = None
    setpoint: float | None = None
    start_temp: float | None = None
    ramp_midpoint_min: float = 2.0
    ramp_steepness: float = 1.0
    sensor_fault: str | None = None
    heater_pwm: float = 0.0
    fan_pwm: float = 0.0
    state: str = "IDLE"
    elapsed_s: float = 0.0
    error: str = ""
    last_update: float = 0.0
    samples: deque = field(default_factory=lambda: deque(maxlen=180))


def clamp(value, low, high):
    return max(low, min(high, value))


def as_float(value, fallback=None):
    if value is None:
        return fallback
    try:
        return float(value)
    except (TypeError, ValueError):
        return fallback


def load_font(size, bold=False):
    family = "DejaVuSans-Bold.ttf" if bold else "DejaVuSans.ttf"
    paths = (
        f"/usr/share/fonts/truetype/dejavu/{family}",
        f"/usr/share/fonts/dejavu/{family}",
        "C:/Windows/Fonts/arialbd.ttf" if bold else "C:/Windows/Fonts/arial.ttf",
    )
    for path in paths:
        try:
            return ImageFont.truetype(path, size)
        except OSError:
            continue
    return ImageFont.load_default()


def load_fonts():
    return {
        "title": load_font(20, bold=True),
        "label": load_font(11, bold=True),
        "small": load_font(10),
        "body": load_font(13),
        "body_bold": load_font(13, bold=True),
        "metric": load_font(22, bold=True),
        "temp": load_font(58, bold=True),
        "state": load_font(16, bold=True),
    }


def text_size(draw, text, font):
    box = draw.textbbox((0, 0), text, font=font)
    return box[2] - box[0], box[3] - box[1]


def draw_card(draw, box, fill=CARD):
    draw.rounded_rectangle(box, radius=8, fill=fill, outline=BORDER, width=1)


def draw_right_text(draw, x, y, text, font, fill):
    width, _ = text_size(draw, text, font)
    draw.text((x - width, y), text, font=font, fill=fill)


def state_color(state):
    return {
        "IDLE": DIM,
        "PREHEAT": AMBER,
        "ROASTING": ORANGE,
        "COOLING": SKY,
        "ERROR": RED,
        "BENCH": SKY,
        "BENCH IDLE": DIM,
    }.get(state, GOLD)


def state_label(state):
    return STATE_LABELS.get(state, state.replace("_", " ").title())


def is_roasting(state):
    return state.state in ("PREHEAT", "ROASTING")


def temp_progress_percent(temp):
    if temp is None:
        return 0.0
    return clamp(((temp - TEMP_MIN) / (TEMP_MAX - TEMP_MIN)) * 100, 0, 100)


def estimate_roast_duration_sec(start_temp, target_temp, midpoint_min, steepness=1.0):
    if start_temp is None or target_temp is None or target_temp <= start_temp:
        return 12 * 60
    for sec in range(0, 30 * 60 + 1, 15):
        if (
            effective_setpoint(start_temp, target_temp, sec, midpoint_min, steepness)
            >= target_temp - 0.5
        ):
            return sec
    return 12 * 60


def build_planned_curve(state, step_sec=20):
    target = state.target
    start = state.start_temp
    if target is None or start is None or target <= 0:
        return []

    duration = estimate_roast_duration_sec(
        start, target, state.ramp_midpoint_min, state.ramp_steepness
    )
    points = []
    for sec in range(0, duration + 1, step_sec):
        points.append(
            (
                sec,
                effective_setpoint(
                    start,
                    target,
                    sec,
                    state.ramp_midpoint_min,
                    state.ramp_steepness,
                ),
            )
        )
    return points


def fmt_number(value, digits=1, empty="--"):
    if value is None:
        return empty
    return f"{value:.{digits}f}"


def fmt_elapsed(seconds):
    seconds = int(max(0, seconds))
    minutes, secs = divmod(seconds, 60)
    return f"{minutes:02d}:{secs:02d}"


def draw_progress(draw, box, percent, color):
    x0, y0, x1, y1 = box
    percent = clamp(float(percent or 0), 0, 100)
    draw.rounded_rectangle(box, radius=4, fill=(42, 37, 32))
    if percent > 0:
        filled = int(x0 + ((x1 - x0) * percent / 100))
        draw.rounded_rectangle((x0, y0, filled, y1), radius=4, fill=color)


def draw_dashed_polyline(draw, points, fill, width=1, dash=5, gap=4):
    if len(points) < 2:
        return
    for index in range(len(points) - 1):
        x0, y0 = points[index]
        x1, y1 = points[index + 1]
        length = math.hypot(x1 - x0, y1 - y0)
        if length == 0:
            continue
        dx = (x1 - x0) / length
        dy = (y1 - y0) / length
        pos = 0.0
        draw_on = True
        while pos < length:
            segment = dash if draw_on else gap
            end = min(pos + segment, length)
            if draw_on:
                draw.line(
                    (x0 + dx * pos, y0 + dy * pos, x0 + dx * end, y0 + dy * end),
                    fill=fill,
                    width=width,
                )
            pos = end
            draw_on = not draw_on


def draw_dashed_hline(draw, x0, x1, y, fill, width=1, dash=6, gap=4):
    draw_dashed_polyline(draw, [(x0, y), (x1, y)], fill, width=width, dash=dash, gap=gap)


def draw_centered_text(draw, box, text, font, fill, y_offset=0):
    x0, y0, x1, y1 = box
    width, height = text_size(draw, text, font)
    x = x0 + ((x1 - x0) - width) // 2
    y = y0 + ((y1 - y0) - height) // 2 + y_offset
    draw.text((x, y), text, font=font, fill=fill)


def draw_temperature_card(draw, state, fonts):
    draw_card(draw, (10, 50, 230, 210))
    draw.text((24, 62), "Temperature", font=fonts["label"], fill=MUTED)

    temp_text = fmt_number(state.temp, 1)
    draw.text((22, 82), temp_text, font=fonts["temp"], fill=TEXT)
    unit_x = 22 + text_size(draw, temp_text, fonts["temp"])[0] + 5
    draw.text((unit_x, 124), "°C", font=fonts["metric"], fill=MUTED)

    if state.sensor_fault:
        fault = f"TC: {state.sensor_fault}"[:30]
        draw.text((24, 158), fault, font=fonts["small"], fill=AMBER)

    progress = temp_progress_percent(state.temp)
    draw_progress(draw, (24, 172, 216, 182), progress, GOLD)
    pct_text = f"{progress:.0f}%"
    pct_w, _ = text_size(draw, pct_text, fonts["body_bold"])
    draw.text((120 - pct_w // 2, 186), pct_text, font=fonts["body_bold"], fill=TEXT)
    draw.text((24, 186), f"{TEMP_MIN}°", font=fonts["small"], fill=DIM)
    draw_right_text(draw, 216, 186, f"{TEMP_MAX}°", fonts["small"], DIM)


def draw_connection_badge(draw, state, fonts):
    draw_card(draw, (240, 50, 470, 92), fill=CARD_ALT)
    color = EMERALD if state.connected else RED
    label = "Online" if state.connected else "Offline"
    draw.ellipse((256, 68, 264, 76), fill=color)
    draw.text((272, 63), label, font=fonts["label"], fill=color)


def draw_mini_stat_card(draw, box, label, value, unit, value_color, fonts):
    draw_card(draw, box)
    x0, y0, x1, y1 = box
    label_w, _ = text_size(draw, label, fonts["small"])
    draw.text((x0 + ((x1 - x0) - label_w) // 2, y0 + 8), label, font=fonts["small"], fill=MUTED)
    value_text = str(value)
    draw_centered_text(draw, (x0, y0 + 18, x1, y1 - 14), value_text, fonts["metric"], value_color)
    unit_w, _ = text_size(draw, unit, fonts["small"])
    draw.text((x0 + ((x1 - x0) - unit_w) // 2, y1 - 18), unit, font=fonts["small"], fill=MUTED)


def draw_state_stat_card(draw, box, state, fonts):
    draw_card(draw, box)
    x0, y0, x1, y1 = box
    label_w, _ = text_size(draw, "State", fonts["small"])
    draw.text((x0 + ((x1 - x0) - label_w) // 2, y0 + 8), "State", font=fonts["small"], fill=MUTED)

    current = state.state or "IDLE"
    label = state_label(current)
    pill_color = state_color(current)
    pill_box = (x0 + 8, y0 + 30, x1 - 8, y1 - 10)
    draw.rounded_rectangle(pill_box, radius=8, fill=(36, 31, 27))
    draw_centered_text(draw, pill_box, label[:12], fonts["small"], pill_color, y_offset=1)


def roast_target_stat(state):
    if is_roasting(state):
        value = fmt_number(state.setpoint, 0)
        target = state.target
        setpoint = state.setpoint
        if target and setpoint and target > setpoint:
            unit = f"°C → {target:.0f}"
        else:
            unit = "°C"
        return "Setpoint", value, unit
    return "Target", fmt_number(state.target, 0), "°C"


def draw_roast_mini_stats(draw, state, fonts):
    label, value, unit = roast_target_stat(state)
    draw_mini_stat_card(draw, (240, 100, 316, 172), label, value, unit, GOLD, fonts)
    draw_mini_stat_card(
        draw,
        (318, 100, 394, 172),
        "Heater",
        f"{state.heater_pwm:.0f}",
        "%",
        TEXT,
        fonts,
    )
    draw_state_stat_card(draw, (396, 100, 470, 172), state, fonts)


def draw_bench_mini_stats(draw, state, fonts):
    draw_mini_stat_card(
        draw,
        (240, 100, 316, 172),
        "Heater",
        f"{state.heater_pwm:.0f}",
        "%",
        ORANGE,
        fonts,
    )
    draw_mini_stat_card(
        draw,
        (318, 100, 394, 172),
        "Fan",
        f"{state.fan_pwm:.0f}",
        "%",
        SKY,
        fonts,
    )
    draw_state_stat_card(draw, (396, 100, 470, 172), state, fonts)


def draw_bench_outputs(draw, state, fonts):
    draw_card(draw, (240, 178, 470, 214))
    draw.text((252, 186), "Outputs", font=fonts["small"], fill=MUTED)
    draw.text((252, 198), "Fan", font=fonts["small"], fill=MUTED)
    draw_progress(draw, (286, 201, 388, 207), state.fan_pwm, SKY)
    draw_right_text(draw, 454, 195, f"{state.fan_pwm:.0f}%", fonts["body_bold"], SKY)
    draw.text((252, 208), "Heat", font=fonts["small"], fill=MUTED)
    draw_progress(draw, (286, 211, 388, 217), state.heater_pwm, ORANGE)
    draw_right_text(draw, 454, 205, f"{state.heater_pwm:.0f}%", fonts["body_bold"], ORANGE)


def chart_y_range(state, live_temps, planned_temps):
    values = [temp for temp in live_temps if temp is not None]
    values.extend(planned_temps)
    if state.target:
        values.append(state.target)
    if not values:
        return 20.0, 230.0
    low = min(values)
    high = max(values)
    if high - low < 8:
        mid = (high + low) / 2
        low = mid - 4
        high = mid + 4
    low -= 2
    high += 2
    return low, high


def draw_chart(draw, state, fonts):
    chart_top = 178 if state.mode == "roast" else 220
    box = (10, chart_top, 470, 310)
    draw_card(draw, box, fill=CHART_BG)
    x0, y0, x1, y1 = box
    if state.mode == "bench":
        draw.text((x0 + 12, y0 + 8), "Temperature", font=fonts["label"], fill=MUTED)
        draw.text((x0 + 12, y0 + 20), "Live trace", font=fonts["small"], fill=DIM)
    else:
        draw.text((x0 + 12, y0 + 8), "Roast Profile", font=fonts["label"], fill=MUTED)
        draw.text((x0 + 12, y0 + 20), "Planned & live", font=fonts["small"], fill=DIM)
    draw_right_text(draw, x1 - 12, y0 + 10, fmt_elapsed(state.elapsed_s), fonts["body_bold"], GOLD)

    chart = (x0 + 12, y0 + 34, x1 - 12, y1 - 10)
    cx0, cy0, cx1, cy1 = chart
    draw.rectangle(chart, outline=(43, 36, 31))
    for i in range(1, 4):
        y = cy0 + ((cy1 - cy0) * i // 4)
        draw.line((cx0, y, cx1, y), fill=(33, 29, 25))

    live = [(t, temp) for t, temp in state.samples if temp is not None]
    planned = build_planned_curve(state) if state.mode == "roast" else []

    if len(live) < 2 and not planned:
        draw.text((cx0 + 12, cy0 + 20), "Waiting for telemetry", font=fonts["body"], fill=DIM)
        return

    t_max = state.elapsed_s + 30
    if live:
        t_max = max(t_max, live[-1][0])
    if planned:
        t_max = max(t_max, planned[-1][0])
    t_max = max(60.0, t_max)

    live_temps = [temp for _, temp in live]
    planned_temps = [temp for _, temp in planned]
    low, high = chart_y_range(state, live_temps, planned_temps)

    def chart_point(t_sec, temp_c):
        x = cx0 + int((cx1 - cx0) * t_sec / t_max)
        y = cy1 - int((cy1 - cy0) * (temp_c - low) / (high - low))
        return x, y

    if state.mode == "roast" and state.target:
        target_y = chart_point(0, state.target)[1]
        draw_dashed_hline(draw, cx0, cx1, target_y, PROFILE_MAX, width=1)

    if planned:
        planned_points = [chart_point(t, temp) for t, temp in planned]
        draw_dashed_polyline(draw, planned_points, GOLD, width=2, dash=6, gap=4)

    if len(live) >= 2:
        live_points = [chart_point(t, temp) for t, temp in live]
        draw.line(live_points, fill=ORANGE, width=2)
        last_x, last_y = live_points[-1]
        draw.ellipse((last_x - 3, last_y - 3, last_x + 3, last_y + 3), fill=TEXT)


def header_subtitle(state):
    if state.error:
        return state.error[:42]
    if state.mode == "bench":
        return "Bench Monitor"
    return "Roast Monitor"


def render_dashboard(state, width, height, fonts):
    image = Image.new("RGB", (width, height), BG)
    draw = ImageDraw.Draw(image)

    for x in range(width):
        blend = x / max(1, width - 1)
        color = (
            int(GOLD[0] * (1 - blend) + ORANGE[0] * blend),
            int(GOLD[1] * (1 - blend) + ORANGE[1] * blend),
            int(GOLD[2] * (1 - blend) + ORANGE[2] * blend),
        )
        draw.line((x, 0, x, 3), fill=color)

    draw.text((14, 14), "Smart Roaster", font=fonts["title"], fill=TEXT)
    draw.text((164, 19), header_subtitle(state), font=fonts["small"], fill=MUTED)
    draw_right_text(draw, width - 12, 17, time.strftime("%H:%M:%S"), fonts["body_bold"], MUTED)

    draw_temperature_card(draw, state, fonts)
    draw_connection_badge(draw, state, fonts)

    if state.mode == "bench":
        draw_bench_mini_stats(draw, state, fonts)
        draw_bench_outputs(draw, state, fonts)
    else:
        draw_roast_mini_stats(draw, state, fonts)

    draw_chart(draw, state, fonts)
    return image


def update_state_from_message(state, message):
    msg_type = message.get("type")
    state.last_update = time.monotonic()
    state.error = ""

    if msg_type == "telemetry":
        prev_state = state.state
        new_state = str(message.get("state", state.state))
        if prev_state == "IDLE" and new_state in ("PREHEAT", "ROASTING"):
            state.samples.clear()
            if state.temp is not None:
                state.start_temp = state.temp
        if new_state == "IDLE":
            state.start_temp = None

        state.temp = as_float(message.get("temp"), state.temp)
        state.target = as_float(message.get("target"), state.target)
        state.setpoint = as_float(message.get("setpoint"), state.setpoint)
        state.ramp_midpoint_min = (
            as_float(message.get("ramp_midpoint_min"), state.ramp_midpoint_min) or 2.0
        )
        state.ramp_steepness = (
            as_float(message.get("ramp_steepness"), state.ramp_steepness) or 1.0
        )
        fault = message.get("sensor_fault")
        state.sensor_fault = str(fault) if fault else None
        state.heater_pwm = clamp(as_float(message.get("heater_pwm"), state.heater_pwm) or 0, 0, 100)
        state.fan_pwm = clamp(as_float(message.get("fan_pwm"), state.fan_pwm) or 0, 0, 100)
        state.elapsed_s = as_float(message.get("timestamp"), state.elapsed_s) or 0.0
        state.state = new_state

        if state.start_temp is None and state.temp is not None and new_state != "IDLE":
            state.start_temp = state.temp
    elif msg_type == "bench_telemetry":
        state.temp = as_float(message.get("temp"), state.temp)
        state.target = None
        state.setpoint = None
        state.sensor_fault = None
        state.heater_pwm = clamp(as_float(message.get("heater_pwm"), state.heater_pwm) or 0, 0, 100)
        state.fan_pwm = clamp(as_float(message.get("fan_pwm"), state.fan_pwm) or 0, 0, 100)
        state.state = "BENCH" if message.get("session_active") else "BENCH IDLE"
    elif msg_type == "bench_result" and "sensors" in message:
        sensors = message["sensors"]
        state.temp = as_float(sensors.get("temp_c"), state.temp)
        state.heater_pwm = clamp(as_float(sensors.get("heater_pwm"), state.heater_pwm) or 0, 0, 100)
        state.fan_pwm = clamp(as_float(sensors.get("fan_pwm"), state.fan_pwm) or 0, 0, 100)
        state.state = "BENCH" if sensors.get("session_active") else "BENCH IDLE"
    elif msg_type == "system_state":
        state.state = str(message.get("state", state.state))
    elif msg_type == "error":
        state.state = "ERROR"
        state.error = str(message.get("msg", "Hardware error"))[:42]

    if state.temp is not None and msg_type in ("telemetry", "bench_telemetry", "bench_result"):
        if msg_type == "telemetry":
            state.samples.append((state.elapsed_s, state.temp))
        else:
            state.samples.append((len(state.samples), state.temp))


def connect_ws(url, mode):
    ws = create_connection(url, timeout=1.0)
    ws.settimeout(0.05)
    if mode == "roast":
        ws.send(json.dumps({"action": "GET_STATE"}))
    return ws


def _sleep_or_stop(seconds, stop_event):
    if stop_event is None:
        time.sleep(seconds)
        return False
    return stop_event.wait(timeout=seconds)


def build_default_args(mode="roast"):
    """Dashboard options aligned with config.py — used when the API starts the LCD."""
    fps = getattr(cfg, "LCD_FPS", 2.0)
    reconnect = getattr(cfg, "LCD_RECONNECT_DELAY_S", 2.0)

    return argparse.Namespace(
        mode=mode,
        ws_url=None,
        fps=fps,
        reconnect_delay=reconnect,
        speed=16_000_000,
        bus=SPI_BUS,
        device=SPI_DEVICE,
        cs_pin=LCD_CS,
        rotation=90,
        backlight=LCD_BACKLIGHT_BRIGHTNESS,
        pixel_brightness=LCD_PIXEL_BRIGHTNESS,
        no_inversion=False,
    )


def add_dashboard_args(parser):
    parser.add_argument(
        "--lcd",
        action="store_true",
        help="Start the SPI LCD dashboard in the same process (stops when the API exits)",
    )
    parser.add_argument("--ws-url", help="Override dashboard WebSocket URL")
    parser.add_argument("--fps", type=float, default=2.0, help="LCD refresh rate")
    parser.add_argument("--reconnect-delay", type=float, default=2.0)
    parser.add_argument("--speed", type=int, default=16_000_000, help="SPI speed in Hz")
    parser.add_argument("--bus", type=int, default=SPI_BUS, help="SPI bus number")
    parser.add_argument(
        "--device", type=int, default=SPI_DEVICE, help="SPI device/chip select number"
    )
    parser.add_argument("--cs-pin", type=int, default=LCD_CS, help="LCD CS BCM GPIO")
    parser.add_argument(
        "--rotation",
        type=int,
        default=90,
        choices=(0, 90, 180, 270),
        help="Display rotation in degrees",
    )
    parser.add_argument(
        "--backlight",
        type=float,
        default=LCD_BACKLIGHT_BRIGHTNESS,
        help="Backlight PWM duty from 0.0 to 1.0",
    )
    parser.add_argument(
        "--pixel-brightness",
        type=float,
        default=LCD_PIXEL_BRIGHTNESS,
        help="Software brightness boost for dashboard frames",
    )
    parser.add_argument(
        "--no-inversion",
        action="store_true",
        help="Disable display inversion",
    )
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

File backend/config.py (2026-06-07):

"""
Central configuration for the coffee roaster hardware and logging.

API settings stay in api/main.py — not configured here.
"""

import os

# Telemetry & control timing
TELEMETRY_INTERVAL_S = 0.5
ROR_WINDOW_SAMPLES = 12
HEATER_CONTROL_WINDOW_S = 1.0

# Safety & state machine (°C)
MAX_SAFE_TEMP_C = 250.0
OVERSHOOT_CUTOFF_C = 15.0
PREHEAT_THRESHOLD_C = 150.0

# Fan stays on until it cools to this temperature after a roast
COOL_DOWN_TEMP_C = 33

# GPIO (BCM pins for gpiozero)
# Heater SSR — GPIO 23 (physical pin 16). LCD backlight is GPIO 22, not 23.
HEATER_GPIO = 23
FAN_PWM_GPIO = 12
FAN_PWM_FREQUENCY_HZ = 1000

# MAX31855 on SPI0 — SCLK 11, MOSI 10, MISO 9 (enable: dtparam=spi=on)
THERMOCOUPLE_CS_GPIO = 7
THERMOCOUPLE_SCLK_GPIO = 11
THERMOCOUPLE_DO_GPIO = 9

# Fan (low-side PWM duty 0.0–1.0; active_high=False in RoasterMotor)
FAN_DEFAULT_SPEED = 1.0

# Soft-start: ramp PWM in steps when the fan turns on (set FAN_RAMP_STEPS = 0 to disable)
FAN_RAMP_STEPS = 15
FAN_RAMP_STEP_DELAY_S = 0.12

# Thermocouple (MAX31855) — raw reading only (no software smoothing)
THERMOCOUPLE_STARTUP_DELAY_S = 0.5

# Main roast API (api/main.py): "mpc" or "pid"
HEATER_CONTROLLER = "mpc"

# Hardware bench initial mode (switchable from the bench UI without restart)
BENCH_DEFAULT_CONTROLLER = "mpc"

# PID — set HEATER_CONTROLLER = "pid" to use
PID_KP = 1.8
PID_KI = 0.09
PID_KD = 0
PID_OUT_MIN = 0.0
PID_OUT_MAX = 100.0
PID_INTEGRAL_LIMIT = 500.0

# MPC — first-order roast model + duty search (see hardware/control/mpc.py)
MPC_AMBIENT_C = 25.0
MPC_MODEL_A = 0.9978
MPC_MODEL_B = 0.0058
MPC_PREDICTION_HORIZON = 120
MPC_DUTY_STEP = 1
MPC_WEIGHT_TRACKING = 5.0
MPC_WEIGHT_HEATER_CHG = 0.01
MPC_WEIGHT_OVERSHOOT = 2.0
MPC_OVERSHOOT_BAND_C = 10.0
MPC_UNSAFE_PENALTY = 100000.0
MPC_OUT_MIN = 0.0
MPC_OUT_MAX = 100.0

# Sigmoid setpoint ramp defaults (see hardware/control/roast_ramp.py)
#   setpoint = span / (1 + exp(-steepness * (t_min - midpoint_min))) + start
DEFAULT_RAMP_MIDPOINT_MIN = 2.0
DEFAULT_RAMP_STEEPNESS = 1.0

# Roast profiles — final target (°C) + sigmoid ramp shape
ROAST_PROFILES = {
    "light": {
        "target_c": 196.0,
        "ramp_midpoint_min": 2.5,
        "ramp_steepness": 0.9,
        "name": "Light",
        "desc": "Fruity & bright",
    },
    "medium": {
        "target_c": 210.0,
        "ramp_midpoint_min": 2.0,
        "ramp_steepness": 1.0,
        "name": "Medium",
        "desc": "Balanced & smooth",
    },
    "medium-dark": {
        "target_c": 220.0,
        "ramp_midpoint_min": 1.8,
        "ramp_steepness": 1.1,
        "name": "Med-Dark",
        "desc": "Rich & full-bodied",
    },
    "dark": {
        "target_c": 230.0,
        "ramp_midpoint_min": 1.6,
        "ramp_steepness": 1.2,
        "name": "Dark",
        "desc": "Bold & smoky",
    },
    "default": {
        "target_c": 210.0,
        "ramp_midpoint_min": DEFAULT_RAMP_MIDPOINT_MIN,
        "ramp_steepness": DEFAULT_RAMP_STEEPNESS,
        "name": "Default",
        "desc": "",
    },
}

# Order shown on the dashboard (default is fallback only, not listed)
ROAST_PROFILE_ORDER = ["light", "medium", "medium-dark", "dark"]


def profile_entry(profile_id):
    return ROAST_PROFILES.get(profile_id) or ROAST_PROFILES["default"]


def target_for_profile(profile_id):
    return float(profile_entry(profile_id)["target_c"])


def ramp_sigmoid_for_profile(profile_id):
    entry = profile_entry(profile_id)
    return {
        "midpoint_min": float(
            entry.get("ramp_midpoint_min", DEFAULT_RAMP_MIDPOINT_MIN)
        ),
        "steepness": float(entry.get("ramp_steepness", DEFAULT_RAMP_STEEPNESS)),
    }


def list_roast_profiles():
    profiles = []
    for profile_id in ROAST_PROFILE_ORDER:
        if profile_id not in ROAST_PROFILES:
            continue
        entry = ROAST_PROFILES[profile_id]
        ramp = ramp_sigmoid_for_profile(profile_id)
        profiles.append(
            {
                "id": profile_id,
                "name": entry["name"],
                "target_c": entry["target_c"],
                "ramp_midpoint_min": ramp["midpoint_min"],
                "ramp_steepness": ramp["steepness"],
                "desc": entry.get("desc", ""),
            }
        )
    return profiles


# Data logging (always under backend/ unless ROASTER_LOG_FOLDER is absolute)
_BACKEND_DIR = os.path.dirname(os.path.abspath(__file__))
_log_dir = os.getenv("ROASTER_LOG_FOLDER", "logs")
LOG_FOLDER = _log_dir if os.path.isabs(_log_dir) else os.path.join(_BACKEND_DIR, _log_dir)
LOG_INDEX_FILE = "roasts_index.csv"
HARDWARE_MODE = os.getenv("ROASTER_HARDWARE_MODE", "pi")

# LCD dashboard — on by default on the Pi; set ROASTER_LCD=0 to disable
_lcd_env = os.getenv("ROASTER_LCD")
if _lcd_env is not None:
    LCD_ENABLED = _lcd_env.lower() in ("1", "true", "yes")
else:
    LCD_ENABLED = HARDWARE_MODE == "pi"
LCD_FPS = 2.0
LCD_RECONNECT_DELAY_S = 2.0

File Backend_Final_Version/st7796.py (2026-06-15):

"""
ST7796 SPI LCD driver for the coffee roaster Raspberry Pi.

Uses SPI1 so transfers do not share SPI0 with the MAX31855 thermocouple.
Heater SSR is GPIO 23. Enable SPI1 with:

    dtoverlay=spi1-1cs,cs0_pin=17

Wiring smoke test (optional):
    python backend/hardware/display/st7796.py
    python backend/hardware/display/st7796.py --image test.jpg
"""

import argparse
import os
import time

try:
    import RPi.GPIO as GPIO
    import spidev
except ImportError as exc:
    raise SystemExit(
        "LCD driver must run on the Raspberry Pi with RPi.GPIO and spidev "
        "installed. Try: pip install spidev RPi.GPIO"
    ) from exc


LCD_NATIVE_WIDTH = 320
LCD_NATIVE_HEIGHT = 480
LCD_ROTATION = 90

SPI_BUS = 1
SPI_DEVICE = 0  # /dev/spidev1.0, with SPI1 CS remapped to BCM GPIO 17

LCD_CS = 17
LCD_RS = 25
LCD_RST = 24
LCD_LED = 22  # GPIO 23 reserved for heater SSR (config.HEATER_GPIO)

LCD_BACKLIGHT_BRIGHTNESS = 1.0  # 0.0–1.0 PWM duty on the backlight pin
LCD_PIXEL_BRIGHTNESS = 1.25  # software boost for images and dashboard frames


class ST7796Display:
    def __init__(
        self,
        width=None,
        height=None,
        rotation=LCD_ROTATION,
        bus=SPI_BUS,
        device=SPI_DEVICE,
        cs_pin=LCD_CS,
        dc_pin=LCD_RS,
        rst_pin=LCD_RST,
        bl_pin=LCD_LED,
        speed_hz=16_000_000,
        backlight_brightness=LCD_BACKLIGHT_BRIGHTNESS,
        display_inversion=True,
    ):
        self.rotation = rotation % 360
        if self.rotation not in (0, 90, 180, 270):
            raise ValueError("rotation must be one of 0, 90, 180, or 270")

        if width is None or height is None:
            if self.rotation in (90, 270):
                self.width = LCD_NATIVE_HEIGHT
                self.height = LCD_NATIVE_WIDTH
            else:
                self.width = LCD_NATIVE_WIDTH
                self.height = LCD_NATIVE_HEIGHT
        else:
            self.width = width
            self.height = height

        self.cs_pin = cs_pin
        self.dc_pin = dc_pin
        self.rst_pin = rst_pin
        self.bl_pin = bl_pin
        self._backlight = max(0.0, min(1.0, float(backlight_brightness)))
        self._display_inversion = display_inversion
        self._bl_pwm = None
        self._bl_pwm_started = False

        dev_path = f"/dev/spidev{bus}.{device}"
        if not os.path.exists(dev_path):
            raise SystemExit(
                f"Cannot find {dev_path}.\n"
                "Enable SPI1 and remap its CS pin away from the heater SSR:\n"
                "  dtparam=spi=on\n"
                "  dtoverlay=spi1-1cs,cs0_pin=17\n"
                "Add those lines to /boot/firmware/config.txt on Raspberry Pi OS "
                "Bookworm, or /boot/config.txt on older releases, then reboot.\n"
                "After reboot, check with: ls -l /dev/spidev*"
            )

        GPIO.setwarnings(False)
        GPIO.setmode(GPIO.BCM)
        for pin in (self.cs_pin, self.dc_pin, self.rst_pin):
            GPIO.setup(pin, GPIO.OUT, initial=GPIO.HIGH)
        GPIO.setup(self.bl_pin, GPIO.OUT)
        self._bl_pwm = GPIO.PWM(self.bl_pin, 1000)

        self.spi = spidev.SpiDev()
        self.spi.open(bus, device)
        self.spi.max_speed_hz = speed_hz
        self.spi.mode = 0
        self.spi.no_cs = True

    def set_backlight(self, duty):
        duty = max(0.0, min(1.0, float(duty)))
        self._backlight = duty
        if self._bl_pwm is None:
            return
        if not self._bl_pwm_started:
            self._bl_pwm.start(duty * 100)
            self._bl_pwm_started = True
        else:
            self._bl_pwm.ChangeDutyCycle(duty * 100)

    def close(self):
        if self._bl_pwm is not None and self._bl_pwm_started:
            self._bl_pwm.stop()
        GPIO.output(self.bl_pin, GPIO.LOW)
        self.spi.close()
        GPIO.cleanup((self.cs_pin, self.dc_pin, self.rst_pin, self.bl_pin))

    def reset(self):
        GPIO.output(self.rst_pin, GPIO.HIGH)
        time.sleep(0.05)
        GPIO.output(self.rst_pin, GPIO.LOW)
        time.sleep(0.12)
        GPIO.output(self.rst_pin, GPIO.HIGH)
        time.sleep(0.12)

    def write_command(self, command, data=None):
        GPIO.output(self.cs_pin, GPIO.LOW)
        GPIO.output(self.dc_pin, GPIO.LOW)
        self.spi.xfer2([command])
        if data:
            GPIO.output(self.dc_pin, GPIO.HIGH)
            self._write_bytes(data)
        GPIO.output(self.cs_pin, GPIO.HIGH)

    def _write_bytes(self, data, chunk_size=4096):
        for start in range(0, len(data), chunk_size):
            self.spi.xfer2(data[start : start + chunk_size])

    def initialize(self):
        madctl_by_rotation = {
            0: 0x48,
            90: 0x28,
            180: 0x88,
            270: 0xE8,
        }

        self.reset()
        self.write_command(0x11)  # Sleep out
        time.sleep(0.12)
        self.write_command(0x3A, [0x55])  # 16-bit RGB565 pixels
        self.write_command(0x36, [madctl_by_rotation[self.rotation]])
        if self._display_inversion:
            self.write_command(0x21)  # Display inversion on, common for IPS panels
        else:
            self.write_command(0x20)
        self.write_command(0x29)  # Display on
        self.set_backlight(self._backlight)
        time.sleep(0.05)
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

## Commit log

2026-05-15 pid controller class
2026-05-15 Added temperature sensor and motor controller classes
2026-05-20 Updated motor software to use new low side switch driver
2026-05-29 Fixed bug where api crashes which turning on the heater
    [config.py, controller.py, manual_control.py]
2026-05-31 Added new control system (MPC) + webserver compatible with our front end
    replace "main" script with the Webserver_2 script to run the MPC script
    [coffeeControlCode - Copy.py, coffeeControlCodeMPC.py, coffeeServer.py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]
2026-06-01 Added fan speed ramping and graphs showing ROR and Temperature
2026-06-06 reverted back to single thermocouple
    [config.py]
2026-06-07 fixed bug where planned setpoint and live setpoint where offset.
    [config.py, controller.py, mock_ui_server.py]
2026-06-08 Data collection, curation, augmentation, Model training, Grayscale calculation
    Includes camera testing, automatic image capture, ROI cropping, dataset splitting, augmentation, CNN training config/scripts, grayscale analysis, batch trend plotting, and English technical documenta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
2026-06-15 AI camera training and inference
2026-06-15 fix camera inference ROI
    [09_pi_camera_inference.py, 10_test_detector_loop.py, pi_ai_detector.py]
2026-06-26 Fix LaTeX formatting for current bean temperatures
    Updated the formatting of the current bean temperature variable in the README.
2026-06-26 Add 3d prints
    [DESKTOP_BASE 2.stl, DESKTOP_COVER_2.stl, DESKTOP_COVER_final.stl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]
